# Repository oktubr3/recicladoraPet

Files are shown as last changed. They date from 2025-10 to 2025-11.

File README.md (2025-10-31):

# 🔄 Máquina Recicladora de PET ♻️➡️✨

## 📖 ¿Qué es este proyecto?

Esta máquina transforma botellas de plástico PET (las de gaseosa) en "hilo" para impresoras 3D.

**¿Cómo funciona?** Es como una máquina de hacer fideos, pero con plástico:
1. Cortás tiras de botellas de plástico
2. La máquina las derrite a 240°C (muy caliente!)
3. Un motor va tirando del plástico derretido
4. Sale un "hilo" perfecto para usar en impresoras 3D

**¡Convertimos basura en algo útil!** 🌍💚

---

## 🏗️ ¿Cómo está hecha?

La máquina tiene **DOS partes principales**:

### Parte 1: El Motor (Tira del plástico)
**"El Tractorcito Inteligente" 🚜**

Esta parte tira del plástico derretido, como cuando sacás masa de pizza estirada.

**¿Qué usa?**
- **Motor NEMA 17**: El "músculo" que tira 💪
- **Driver A4988**: Convierte las señales del Arduino en potencia para el motor
- **Arduino Uno**: El "cerebro" que controla todo 🧠
- **Potenciómetro**: Una perilla para controlar la velocidad (como el volumen de la radio)
- **Botón**: Para cambiar la dirección (adelante/atrás)

**¿Qué hace especial?**
- Se mueve SÚPER suave (microstepping 1/16 = pasos 16 veces más pequeños)
- Acelera y frena de forma gradual (no se sacude)
- Podés controlar la velocidad de 0% a 100%

---

### Parte 2: El Calentador (Derrite el plástico)
**"La Cocina de Plástico" 🔥**

Esta parte derrite el plástico PET a 240°C (la temperatura perfecta).

**¿Qué usa?**
- **Hotend V6**: El "horno" que calienta
- **Termistor NTC 100k**: Un "termómetro electrónico" que mide la temperatura
- **Módulo MOSFET**: Un interruptor electrónico que controla cuánta potencia darle al calentador
- **Display LCD**: Una pantallita que muestra la temperatura 📺
- **3 Botones**: Para prender/apagar y subir/bajar la temperatura

**¿Qué hace especial?**
- **Control PID profesional**: Como las impresoras 3D caras (Prusa)
- Llega exactamente a la temperatura que querés (±2-3°C de precisión)
- No se pasa ni se queda corta

---

## 📋 ¿Qué materiales necesito?

### Electrónica:
- [ ] 🧠 Arduino Uno (el cerebro)
- [ ] 💪 Motor NEMA 17 (modelo 17HS2408)
- [ ] 🎮 Driver A4988 (controla el motor)
- [ ] 📺 Display LCD 16x2 con I2C (la pantallita)
- [ ] ⚡ Módulo MOSFET (para controlar el calentador)
- [ ] 🌡️ Termistor NTC 100K (el termómetro)
- [ ] 🎚️ Potenciómetro 10K (la perilla de velocidad)
- [ ] 🔘 4 Botones pulsadores

### Componentes importantes:
- [ ] 🔥 Hotend V6 (el calentador)
- [ ] 🔌 Fuente de alimentación 24V
- [ ] 🔽 Módulo Step-down LM2596 (convierte 24V a 12V)
- [ ] 🔧 Resistencia 4.7kΩ (para el termómetro)
- [ ] ⭐ Resistencia 2.2kΩ (evita que el motor vibre al encender)
- [ ] 🔗 Cable jumper (para conectar 2 pines del A4988)
- [ ] 🛑 Botón de emergencia (para cortar todo en caso de problema)

---

## 🚀 ¿Cómo lo instalo?

### Paso 1: Instalar el programa Arduino IDE 💻
1. 📥 Descargá Arduino IDE desde [arduino.cc](https://www.arduino.cc)
2. 🖱️ Instalalo en tu computadora

### Paso 2: Descargar este proyecto 📦
1. 📥 Descargá este proyecto (botón verde "Code" → "Download ZIP")
2. 📂 Descomprimí el archivo ZIP

### Paso 3: Instalar la biblioteca del display 📚
1. 🖥️ Abrí Arduino IDE
2. 🔧 Andá a: **Herramientas** → **Administrar Bibliotecas**
3. 🔍 Buscá: **"LiquidCrystal I2C"**
4. ✅ Instalá la versión de **Frank de Brabander**

### Paso 4: Subir el código al Arduino ⬆️
1. 📄 Abrí el archivo: `MaquinaRecicladoraPet/MaquinaRecicladoraPet.ino`
2. 🔌 Conectá tu Arduino a la computadora con el cable USB
3. ⚙️ Seleccioná: **Herramientas** → **Placa** → **Arduino Uno**
4. 🔌 Seleccioná: **Herramientas** → **Puerto** → (el puerto donde está tu Arduino)
5. ➡️ Hacé click en el botón **"➜"** (Subir) y esperá ⏳

---

## ⚠️ IMPORTANTE: Configuración de Hardware

### 🔊 Problema común: Motor vibra al encender

Cuando encendés el Arduino, durante los primeros 3 segundos el motor puede vibrar o girar solo. Esto pasa porque los cables "flotan" (no tienen un valor definido) hasta que el programa arranca.

**✅ Solución (OBLIGATORIA):**

#### 1. 🔗 Conectar dos pines del A4988 juntos
En el módulo A4988, buscá los pines **RST** y **SLP** (están uno al lado del otro). Conectalos con un cable o jumper.

#### 2. ⭐ Agregar una resistencia al pin STEP

Esta es LA SOLUCIÓN más importante:

```
                    Cable del Arduino
Arduino D3 ────────────────────┐
                                │
                                ├──── Pin STEP del A4988
                                │
                           [Resistencia
                            2.2kΩ]
                                │
                               GND (tierra)
```

**¿Cómo se conecta?**
- **NO desconectes** el cable que va del Arduino al A4988
- **Agregá** una resistencia de 2.2kΩ entre el pin STEP del A4988 y GND
- La resistencia va "en paralelo" (al costado), no corta el cable
- Podés usar resistencias de: 2.2kΩ, 4.7kΩ o 10kΩ

**¿Por qué funciona?**
La resistencia "tira" el pin hacia GND (0 voltios) cuando el Arduino no está mandando señales. Así el motor no se mueve durante el arranque.

#### 3. 🎯 Conectar los pines de microstepping (IMPORTANTE para movimiento suave)

El microstepping hace que el motor se mueva SÚPER suave, sin vibraciones. Tenés que conectar:

- 📍 **Arduino D8** → **MS1** del A4988
- 📍 **Arduino D12** → **MS2** del A4988
- 📍 **Arduino D13** → **MS3** del A4988

Estos 3 pines le dicen al motor que se mueva en pasos 16 veces más pequeños (3200 pasos por vuelta en vez de 200). ¡Por eso el movimiento es tan suave!

---

## 🎮 ¿Cómo se usa?

### 🎚️ Controlar la velocidad del motor:
- 🔄 Girá el **potenciómetro** (la perilla)
- ➡️ Hacia la derecha = más rápido 🏃
- ⬅️ Hacia la izquierda = más lento 🐢
- 🛑 Si lo ponés en 0%, el motor se apaga solo

### 🔀 Cambiar la dirección:
- 🔘 Presioná el **botón conectado al pin D4**
- ↔️ El motor cambia entre adelante y atrás

### 🌡️ Controlar la temperatura:
- 🔘 **Botón conectado al pin D5**: Prender/Apagar el calentador 🔥
- 🔘 **Botón conectado al pin D6**: Bajar temperatura (de a 5°C) ❄️
- 🔘 **Botón conectado al pin D7**: Subir temperatura (de a 5°C) 🔥
- 🎯 Temperatura inicial: **240°C** (perfecta para PET)

### 📺 Leer el display:
**Pantalla normal** (muestra la temperatura):
```
T:240.0C  [ON]
Obj:240C
```
- 🌡️ **T:** = Temperatura actual
- 🔥 **[ON]** = Está calentando
- ✅ **[--]** = Está en la temperatura correcta (esperando)
- ⭕ **[OFF]** = Apagado
- 🎯 **Obj:** = Temperatura objetivo

**Pantalla temporal** (cuando ajustás la velocidad):
```
Velocidad:  50%
Dir: Adelante
```
o
```
Velocidad:  50%
Dir: Atras
```
⏱️ Esta pantalla se muestra por 3 segundos cuando tocás el potenciómetro o el botón de dirección.

---

## 🔧 Solución de problemas

### 🔊 El motor vibra cuando enciendo el Arduino

**❓ Causa:** Los cables "flotan" durante los primeros 3 segundos del arranque.

**✅ Solución:**
1. ❓ ¿Conectaste los pines **RST y SLP** del A4988?
2. ❓ ¿Agregaste la **resistencia 2.2kΩ** entre STEP y GND?
3. ❓ ¿La resistencia está en **paralelo** (no corta el cable del Arduino)?

✨ Si hiciste todo eso, el motor NO debería moverse al encender.

---

### 🔊 El motor vibra TODO el tiempo

**❓ Posibles causas:**
1. **⚙️ Microstepping mal configurado:**
   - Verificá que los pines **D8, D12, D13** del Arduino estén conectados a **MS1, MS2, MS3** del A4988
   - Estos pines controlan el modo de microstepping (1/16 step = movimiento súper suave)

2. **⚡ Poca corriente:**
   - El potenciómetro del A4988 (VREF) debe estar en 0.8V
   - Si no tenés multímetro, giralo POQUITO en sentido horario

3. **🔗 RST y SLP no conectados:**
   - Verificá que esos dos pines estén conectados con un jumper

---

### 📺 El display no muestra nada

**✅ Soluciones:**
1. **🎚️ Ajustar el contraste:** En la parte de atrás del display hay un potenciómetro chiquito. Giralo hasta que veas las letras.
2. **📍 Dirección I2C incorrecta:**
   - 🖥️ Abrí el código en Arduino IDE
   - 🔍 Buscá la línea 34: `LiquidCrystal_I2C lcd(0x27, 16, 2);`
   - 🔄 Cambiá `0x27` por `0x3F`
   - ⬆️ Volvé a subir el código

---

### 🌡️ La temperatura no es correcta

1. 🔍 **Verificá las conexiones del termistor** (el sensor de temperatura)
2. 🔧 **Verificá la resistencia de 4.7kΩ** (debe estar bien conectada)
3. 🏠 La temperatura ambiente debería mostrar entre 18°C y 25°C

---

## 📊 Datos técnicos (para los curiosos) 🤓

### 🎮 Motor:
- ⚙️ **Pasos por vuelta:** 3200 (con microstepping 1/16)
- 🏃 **Velocidad:** Ajustable de 100 a 2000 RPM
- ✨ **Suavidad:** Movimiento ultra suave, sin vibraciones
- 🚀 **Aceleración:** Gradual (no se sacude al arrancar/frenar)

### 🌡️ Temperatura:
- 📏 **Rango:** 0°C a 270°C
- 🎯 **Precisión:** ±2-3°C
- 🧠 **Control:** PID profesional (como impresoras 3D Prusa)
- 🔥 **Temperatura para PET:** 240°C

### 📺 Display:
- 📐 **Tamaño:** 16 caracteres × 2 líneas
- ⚡ **Actualización:** Cada 0.2 segundos (sin parpadeo)

---

## 🛡️ Seguridad

**⚠️ IMPORTANTE - LEÉ ESTO:**

1. 🔥 **El calentador llega a 240°C** (¡puede quemarte!):
   - 🚫 NO lo toques cuando está encendido
   - ⏰ Esperá 10 minutos después de apagar para que se enfríe

2. 🛑 **Botón de emergencia**:
   - ✅ Siempre tené el botón de emergencia conectado
   - ⚡ Si algo sale mal, presionalo y corta toda la energía

3. 👨‍👩‍👧 **Supervisión de un adulto**:
   - ⚠️ Este proyecto usa temperaturas altas y electricidad
   - 🤝 Pedile a un adulto que te supervise

4. 💨 **Ventilación**:
   - 🪟 Usá la máquina en un lugar ventilado
   - 👃 El plástico derretido puede tener olor

---

## 🎓 ¿Querés aprender más?

### 🤖 Sobre Arduino:
- 📚 [Documentación oficial de Arduino](https://www.arduino.cc/reference/es/)
- 🎥 [Tutoriales en español](https://www.arduino.cc/en/Tutorial/HomePage)

### ♻️ Sobre el PET:
- 🔬 [¿Qué es el PET?](https://es.wikipedia.org/wiki/Tereftalato_de_polietileno)
- 🥤 El PET es el plástico de las botellas de gaseosa
- 🌡️ Se derrite a 240-260°C

### 🌍 Sobre reciclaje:
- ♻️ [Precious Plastic](https://preciousplastic.com/) - Proyecto de reciclaje de plástico global
- 🤖 [Recyclebot](https://www.appropedia.org/Recyclebot) - Máquinas similares

---

## 💚 Misión del proyecto

**🌍 Queremos ayudar al planeta** convirtiendo botellas de plástico (que iban a la basura) en material útil para crear cosas nuevas con impresoras 3D.

Si cada persona recicla sus botellas, podemos:
- 🗑️ Reducir la basura plástica
- 🎨 Crear material útil
- 💰 Ahorrar dinero
- 🌳 Proteger el medio ambiente

**¡Juntos podemos convertir la basura en tesoros!** 🌍♻️✨

---

## 📄 Licencia

Este proyecto es **libre y gratuito** (Licencia MIT). Podés:
- ✅ Usarlo para lo que quieras
- 🔧 Modificarlo
- 🤝 Compartirlo
- 🏗️ Construir tu propia máquina

---

## 👥 Créditos

Creado con ❤️ para ayudar al planeta 🌍 y enseñar programación 💻.

---

**❓ ¿Preguntas? 🐛 ¿Problemas? 💡 ¿Mejoras?**
Abrí un "Issue" en GitHub y te ayudamos! 🚀

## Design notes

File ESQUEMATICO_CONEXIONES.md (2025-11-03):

# 🔌 Esquemático de Conexiones - Máquina Recicladora PET

## 📋 Tabla de Conexiones Completa

### 🎮 Motor NEMA 17 + Driver A4988

| Arduino Pin | →  | A4988 Pin | Descripción |
|---|---|---|---|
| **D2** | → | **DIR** | Dirección del motor (adelante/atrás) |
| **D3** | → | **STEP** | Pasos del motor (cada pulso = 1 paso) |
| **D8** | → | **MS1** | Microstepping bit 1 |
| **D12** | → | **MS2** | Microstepping bit 2 |
| **D13** | → | **MS3** | Microstepping bit 3 |
| **5V** | → | **VDD** | Alimentación lógica del driver |
| **GND** | → | **GND** | Tierra común |

**⚠️ IMPORTANTE - Resistencia Pull-Down:**
```
Pin STEP (A4988) ──┬──→ Arduino D3
                   │
              [Resistencia
               2.2kΩ]
                   │
                  GND
```

**🔗 Jumper RST-SLP:**
- Conectar con un cable jumper: **RST ↔ SLP** (pines del A4988)

**⚡ Alimentación del motor:**
- **12V+** → **VMOT** del A4988
- **GND** → **GND** del A4988

**🔌 Salidas del motor:**
- A4988 **1A, 1B, 2A, 2B** → Motor NEMA 17 (4 cables)

---

### 🌡️ Sistema de Calefacción (Hotend V6)

| Componente | Pin | →  | Destino |
|---|-----|---|---|
| **Termistor NTC 100K** | Cable 1 | → | **A1** (Arduino) |
| **Termistor NTC 100K** | Cable 2 | → | **5V** |
| **Resistencia 4.7kΩ** | Terminal 1 | → | **A1** (Arduino) |
| **Resistencia 4.7kΩ** | Terminal 2 | → | **GND** |

**Circuito del Termistor:**
```
5V ─────┬──── Termistor ────┬──── A1 (Arduino)
        │                    │
        │              [Resistencia
        │                4.7kΩ]
        │                    │
        └────────────────────┴──── GND
```

| Módulo MOSFET | Pin | →  | Destino |
|---|-----|---|---|
| **MOSFET** | Signal (S) | → | **D11** (Arduino - PWM) |
| **MOSFET** | VCC | → | **5V** (Arduino) |
| **MOSFET** | GND | → | **GND** (Arduino) |
| **MOSFET** | V+ | → | **24V+** (Fuente) |
| **MOSFET** | V- | → | **GND** (Fuente) |
| **MOSFET** | OUT+ | → | **Hotend V6 +** |
| **MOSFET** | OUT- | → | **Hotend V6 -** |

---

### 📺 Display LCD 16x2 con I2C

| LCD I2C | Pin | →  | Arduino Pin |
|---|-----|---|---|
| **VCC** | | → | **5V** |
| **GND** | | → | **GND** |
| **SDA** | | → | **A4** (o pin SDA) |
| **SCL** | | → | **A5** (o pin SCL) |

---

### 🎚️ Potenciómetro (Control de Velocidad)

| Potenciómetro 10K | Pin | →  | Destino |
|---|-----|---|---|
| Terminal 1 | | → | **GND** |
| Terminal central (wiper) | | → | **A0** (Arduino) |
| Terminal 3 | | → | **5V** |

---

### 🔘 Botones de Control

| Botón | Pin | →  | Arduino Pin | Función |
|---|-----|---|---|---|
| **Botón 1** | Terminal 1 | → | **D4** | Cambiar dirección motor |
| **Botón 1** | Terminal 2 | → | **GND** | |
| **Botón 2** | Terminal 1 | → | **D5** | ON/OFF calefactor |
| **Botón 2** | Terminal 2 | → | **GND** | |
| **Botón 3** | Terminal 1 | → | **D6** | Bajar temperatura (-5°C) |
| **Botón 3** | Terminal 2 | → | **GND** | |
| **Botón 4** | Terminal 1 | → | **D7** | Subir temperatura (+5°C) |
| **Botón 4** | Terminal 2 | → | **GND** | |

**📝 Nota:** Los botones usan la resistencia pull-up interna del Arduino (INPUT_PULLUP), por eso van directo a GND.

---

### ⚡ Sistema de Alimentación

| Fuente | Salida | →  | Destino |
|---|---|---|---|
| **Fuente 24V** | 24V+ | → | VMOT (A4988) + Entrada Step-Down |
| **Fuente 24V** | GND | → | GND común |
| **Step-Down LM2596** | Entrada | ← | 24V (Fuente) |
| **Step-Down LM2596** | Salida 12V | → | Arduino Vin |
| **Step-Down LM2596** | GND | → | GND común |

---

## 🎨 Diagrama Visual Simplificado

```
                    ARDUINO UNO
        ┌──────────────────────────────────┐
        │                                  │
        │  D2  ────────────→ DIR (A4988)  │
        │  D3  ─┬──────────→ STEP (A4988) │
        │       │                          │
        │       └─[2.2kΩ]─→ GND            │
        │                                  │
        │  D4  ←───[Botón]──→ GND          │
        │  D5  ←───[Botón]──→ GND          │
        │  D6  ←───[Botón]──→ GND          │
        │  D7  ←───[Botón]──→ GND          │
        │                                  │
        │  D8  ────────────→ MS1 (A4988)   │
        │  D11 ────────────→ MOSFET Signal │
        │  D12 ────────────→ MS2 (A4988)   │
        │  D13 ────────────→ MS3 (A4988)   │
        │                                  │
        │  A0  ←───[Pot]────┬─ 5V          │
        │                   └─ GND         │
        │                                  │
        │  A1  ←───[Termistor + 4.7kΩ]─┬─ 5V
        │                               └─ GND
        │                                  │
        │  A4  ←─────────── SDA (LCD)      │
        │  A5  ←─────────── SCL (LCD)      │
        │                                  │
        │  5V  ────┬────────────────────   │
        │          ├→ LCD VCC              │
        │          ├→ A4988 VDD            │
        │          ├→ MOSFET VCC           │
        │          └→ Pot + Termistor      │
        │                                  │
        │  GND ────┴────────────────────   │
        │          └→ Común a todos        │
        │                                  │
        │  Vin ←─── 12V (Step-Down)        │
        └──────────────────────────────────┘

        A4988 Driver
        ┌──────────────┐
        │ VMOT ← 24V   │
        │ GND  ← GND   │
        │ 1A,1B,2A,2B  │──→ NEMA 17
        │ RST↔SLP      │ (con jumper)
        └──────────────┘

        MOSFET Module
        ┌──────────────┐
        │ V+ ← 24V     │
        │ V- ← GND     │
        │ OUT+,OUT-    │──→ Hotend V6
        └──────────────┘
```

---

## ✅ Lista de Verificación de Conexiones

Antes de encender, verificá:

- [ ] 🔌 Todos los GND están conectados (tierra común)
- [ ] ⚡ Fuente de 24V conectada correctamente
- [ ] 🔽 Step-down configurado en 12V de salida
- [ ] 🔗 Resistencia 2.2kΩ entre STEP y GND (pull-down)
- [ ] 🔗 Jumper RST-SLP en el A4988
- [ ] 📍 Pines MS1, MS2, MS3 conectados (D8, D12, D13)
- [ ] 🌡️ Termistor con resistencia 4.7kΩ a GND
- [ ] 📺 Display I2C en pines correctos (A4=SDA, A5=SCL)
- [ ] 🔘 Los 4 botones conectados a GND
- [ ] 🎚️ Potenciómetro entre GND y 5V, centro a A0
- [ ] 🔥 Hotend conectado al MOSFET (respetando polaridad)
- [ ] 💪 Motor NEMA 17 conectado al A4988

---

## 🎯 Configuración del Driver A4988

### Ajuste de Corriente (VREF)

El potenciómetro pequeño en el A4988 controla la corriente del motor:

**Para NEMA 17 (17HS2408):**
- **VREF recomendado:** 0.8V
- **Fórmula:** VREF = Corriente_motor × 8 × R_sense
- Para 1A: VREF = 1.0 × 8 × 0.1 = 0.8V

**🔧 Cómo medir:**
1. Conectá el multímetro en modo voltaje DC
2. Cable negro (COM) → GND del A4988
3. Cable rojo → Tornillo del potenciómetro
4. Girá el potenciómetro hasta ver 0.8V
5. Girá en sentido horario para aumentar
6. Girá en sentido antihorario para disminuir

---

## 🛡️ Seguridad

⚠️ **IMPORTANTE:**

1. **SIEMPRE desconectá la alimentación** antes de hacer cambios
2. **Verificá polaridad** del hotend y motor antes de conectar
3. **NO toques** el A4988 ni el hotend cuando estén encendidos (se calientan mucho)
4. **Botón de emergencia:** Mantené un botón para cortar la alimentación rápidamente
5. **Ventilación:** Trabajá en un lugar ventilado
6. **Supervisión adulta:** Este proyecto maneja altas temperaturas y voltajes

---

## 📸 Fotos Recomendadas (para agregar después)

Para hacer este manual más completo, sería útil agregar fotos de:
- [ ] Conexiones del A4988 con todos los cables
- [ ] Circuito del termistor con la resistencia
- [ ] Módulo MOSFET conectado
- [ ] Display LCD con cables I2C
- [ ] Potenciómetro conectado
- [ ] Vista general del circuito armado

---

**✨ Con estas conexiones, tu máquina recicladora estará lista para funcionar!**

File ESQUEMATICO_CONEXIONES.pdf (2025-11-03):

## 🔌 Esquemático de Conexiones - Máquina Recicladora PET

### 📋 Tabla de Conexiones Completa

🎮 Motor NEMA 17 + Driver A4988

Arduino Pin | → | A4988 Pin | Descripción
D2 | → | DIR | Dirección del motor (adelante/atrás)
D3 | → | STEP | Pasos del motor (cada pulso = 1 paso)
D8 | → | MS1 | Microstepping bit 1
D12 | → | MS2 | Microstepping bit 2
D13 | → | MS3 | Microstepping bit 3
5V | → | VDD | Alimentación lógica del driver
GND | → | GND | Tierra común

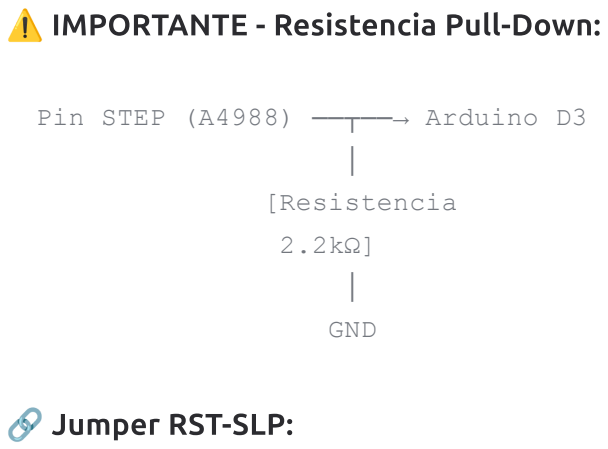
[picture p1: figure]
⚠️ IMPORTANTE - Resistencia Pull-Down:; 🔗 Jumper RST-SLP:; Pin STEP (A4988) ──┬──→ Arduino D3 │ [Resistencia 2.2kΩ] │ GND

Conectar con un cable jumper: RST ↔ SLP (pines del A4988)

⚡ Alimentación del motor:

12V+ → VMOT del A4988

GND → GND del A4988

🔌 Salidas del motor:

A4988 1A, 1B, 2A, 2B → Motor NEMA 17 (4 cables)

️ Sistema de Calefacción (Hotend V6)

Componente | Pin | → | Destino
Termistor NTC 100K | Cable 1 | → | A1 (Arduino)
Termistor NTC 100K | Cable 2 | → | 5V
Resistencia 4.7kΩ | Terminal 1 | → | A1 (Arduino)
Resistencia 4.7kΩ | Terminal 2 | → | GND

Circuito del Termistor:

Módulo MOSFET | Pin | → | Destino
MOSFET | Signal (S) | → | D11 (Arduino - PWM)
MOSFET | VCC | → | 5V (Arduino)
MOSFET | GND | → | GND (Arduino)
MOSFET | V+ | → | 24V+ (Fuente)
MOSFET | V- | → | GND (Fuente)
MOSFET | OUT+ | → | Hotend V6 +
MOSFET | OUT- | → | Hotend V6 -

📺 Display LCD 16x2 con I2C

## 5V ─────┬──── Termistor ────┬──── A1 (Arduino)

│ | │
│ | [Resistencia
│ | 4.7kΩ]
│ | │

## └────────────────────┴──── GND

LCD I2C | Pin | → | Arduino Pin
VCC | | → | 5V
GND | | → | GND
SDA | | → | A4 (o pin SDA)
SCL | | → | A5 (o pin SCL)

️ Potenciómetro (Control de Velocidad)

Potenciómetro 10K | Pin | → | Destino
Terminal 1 | | → | GND
Terminal central (wiper) | | → | A0 (Arduino)
Terminal 3 | | → | 5V

🔘 Botones de Control

Botón | Pin | → | Arduino Pin | Función
Botón 1 | Terminal 1 | → | D4 | Cambiar dirección motor
Botón 1 | Terminal 2 | → | GND
Botón 2 | Terminal 1 | → | D5 | ON/OFF calefactor
Botón 2 | Terminal 2 | → | GND
Botón 3 | Terminal 1 | → | D6 | Bajar temperatura (-5°C)
Botón 3 | Terminal 2 | → | GND
Botón 4 | Terminal 1 | → | D7 | Subir temperatura (+5°C)

Botón | Pin | → | Arduino Pin | Función
Botón 4 | Terminal 2 | → | GND

📝 Nota: Los botones usan la resistencia pull-up interna del Arduino (INPUT_PULLUP), por eso van

directo a GND.

⚡ Sistema de Alimentación

Fuente | Salida | → | Destino
Fuente 24V | 24V+ | → | VMOT (A4988) + Entrada Step-Down
Fuente 24V | GND | → | GND común
Step-Down LM2596 | Entrada | ← | 24V (Fuente)
Step-Down LM2596 | Salida 12V | → | Arduino Vin
Step-Down LM2596 | GND | → | GND común

### 🎨 Diagrama Visual Simplificado

## ARDUINO UNO

┌──────────────────────────────────┐
│ | | │

## │ D2 ────────────→ DIR (A4988) │ │ D3 ─┬──────────→ STEP (A4988) │

│ | │ | │
│ | └─[2.2kΩ]─→ GND | │
│ | | │
│ D4 ←───[Botón]──→ GND | │
│ D5 ←───[Botón]──→ GND | │
│ D6 ←───[Botón]──→ GND | │
│ D7 ←───[Botón]──→ GND | │
│ | | │
│ D8 ────────────→ MS1 (A4988) | │

## │ D11 ────────────→ MOSFET Signal │

### ✅ Lista de Verificación de Conexiones

Antes de encender, verificá:

│ D12 ────────────→ MS2 (A4988) | │
│ D13 ────────────→ MS3 (A4988) | │
│ | | │
│ A0 ←───[Pot]────┬─ 5V | │
│ | └─ GND | │
│ | | │

## │ A1 ←───[Termistor + 4.7kΩ]─┬─ 5V

│ | | └─ GND
│ | | │
│ A4 ←─────────── SDA (LCD) | │
│ A5 ←─────────── SCL (LCD) | │
│ | | │
│ 5V ────┬──────────────────── | │
│ | ├→ LCD VCC | │
│ | ├→ A4988 VDD | │
│ | ├→ MOSFET VCC | │
│ | └→ Pot + Termistor | │
│ | | │
│ GND ────┴──────────────────── | │
│ | └→ Común a todos | │
│ | | │
│ Vin ←─── 12V (Step-Down) | │
└──────────────────────────────────┘

## A4988 Driver

┌──────────────┐
│ VMOT ← 24V | │
│ GND ← GND | │

## │ 1A,1B,2A,2B │──→ NEMA 17

│ RST↔SLP | │ (con jumper)
└──────────────┘

## MOSFET Module

┌──────────────┐
│ V+ ← 24V | │
│ V- ← GND | │
│ OUT+,OUT- | │──→ Hotend V6
└──────────────┘

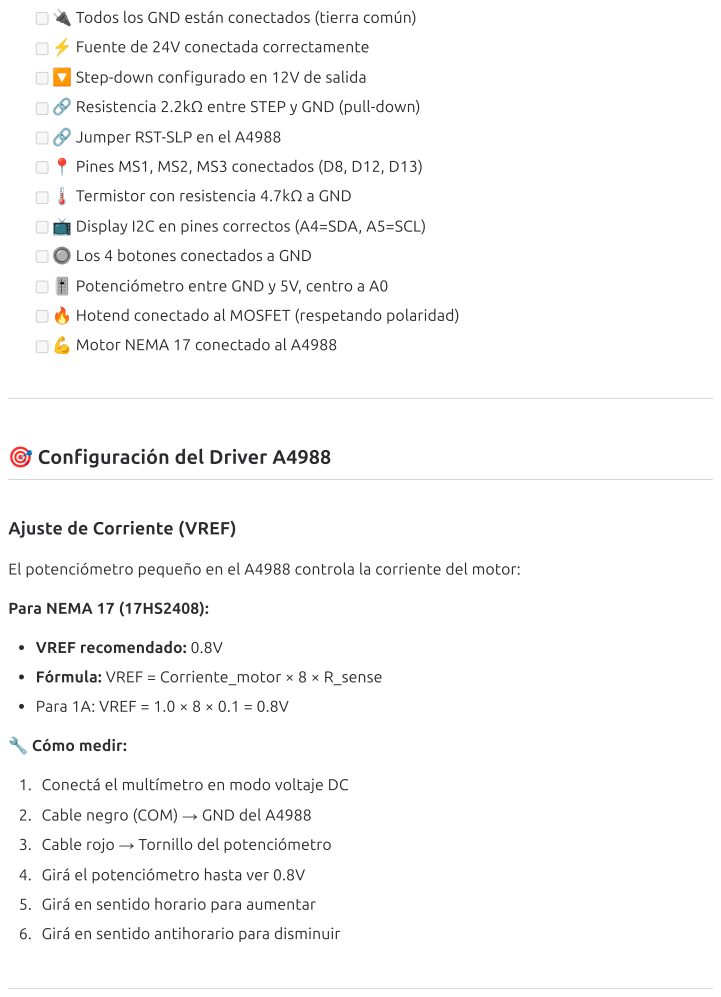
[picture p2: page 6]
📍 Pines MS1, MS2, MS3 conectados (D8, D12, D13); Para NEMA 17 (17HS2408):; VREF recomendado: 0.8V; Fórmula: VREF = Corriente_motor × 8 × R_sense; Para 1A: VREF = 1.0 × 8 × 0.1 = 0.8V; 🔧 Cómo medir:

🔌 Todos los GND están conectados (tierra común)

⚡ Fuente de 24V conectada correctamente

🔽 Step-down configurado en 12V de salida

🔗 Resistencia 2.2kΩ entre STEP y GND (pull-down)

🔗 Jumper RST-SLP en el A4988

️ Termistor con resistencia 4.7kΩ a GND

📺 Display I2C en pines correctos (A4=SDA, A5=SCL)

🔘 Los 4 botones conectados a GND

️ Potenciómetro entre GND y 5V, centro a A0

🔥 Hotend conectado al MOSFET (respetando polaridad)

💪 Motor NEMA 17 conectado al A4988

🎯 Configuración del Driver A4988

Ajuste de Corriente (VREF)

El potenciómetro pequeño en el A4988 controla la corriente del motor:

1. Conectá el multímetro en modo voltaje DC

2. Cable negro (COM) → GND del A4988

3. Cable rojo → Tornillo del potenciómetro

4. Girá el potenciómetro hasta ver 0.8V

5. Girá en sentido horario para aumentar

6. Girá en sentido antihorario para disminuir

### ️ Seguridad

⚠️ IMPORTANTE:

1. SIEMPRE desconectá la alimentación antes de hacer cambios
2. Verificá polaridad del hotend y motor antes de conectar
3. NO toques el A4988 ni el hotend cuando estén encendidos (se calientan mucho)
4. Botón de emergencia: Mantené un botón para cortar la alimentación rápidamente
5. Ventilación: Trabajá en un lugar ventilado
6. Supervisión adulta: Este proyecto maneja altas temperaturas y voltajes

### 📸 Fotos Recomendadas (para agregar después)

Para hacer este manual más completo, sería útil agregar fotos de:

Conexiones del A4988 con todos los cables

Circuito del termistor con la resistencia

Módulo MOSFET conectado

Display LCD con cables I2C

Potenciómetro conectado

Vista general del circuito armado

✨ Con estas conexiones, tu máquina recicladora estará lista para funcionar!

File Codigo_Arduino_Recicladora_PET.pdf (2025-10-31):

// ============================================
// 🎯 ¡MÁQUINA RECICLADORA DE BOTELLAS DE PLÁSTICO!
// ============================================
// Este programa controla una máquina que transforma botellas de plástico PET
// en "hilo" para impresoras 3D. ¡Es como una máquina de hacer fideos, pero con plástico! //
// La máquina tiene 2 partes principales:
// 1. Un MOTOR que tira del plástico derretido (como tirar masa de pizza)
// 2. Un CALEFACTOR que derrite el plástico a 240°C (como un horno)
//
// El Arduino es el "cerebro" que controla todo automáticamente.
// ============================================

// ============================================
// PASO 1: INCLUIR LIBRERÍAS
// ============================================
// Las librerías son como "cajas de herramientas" que otras personas ya hicieron
// y nosotros podemos usar. Nos ahorran mucho trabajo.
#include <Wire.h> | // Esta librería permite hablar con el display por I2C

// I2C es como un "idioma" que usa solo 2 cables para comunicarse

#include <LiquidCrystal_I2C.h> // Esta librería controla el display LCD (la pantallita) // LCD = Liquid Crystal Display (pantalla de cristal líquido)

// ============================================
// PASO 2: CONFIGURAR EL DISPLAY LCD
// ============================================
// Creamos un objeto llamado "lcd" que representa nuestra pantalla.
// Es como ponerle un nombre a la pantalla para poder hablarle.

LiquidCrystal_I2C lcd(0x27, 16, 2); // 0x27 es la "dirección" del display (como una dirección de casa)
// 16 = tiene 16 columnas (16 letras por fila) // 2 = tiene 2 filas (2 líneas de texto)
// Si no funciona, prueba cambiar 0x27 por 0x3F

// ============================================
// PASO 3: DEFINIR LOS PINES DEL MOTOR
// ============================================
// Los "pines" son como los enchufes del Arduino donde conectamos cables. // Cada pin tiene un número, como si fueran "apartamentos" numerados.

const int dirPin = 2; // Pin número 2: controla la DIRECCIÓN del motor // Le dice al motor si debe girar hacia adelante o hacia atrás // "const" significa que este número NUNCA va a cambiar

const int stepPin = 3; // Pin número 3: controla los PASOS del motor // Cada vez que este pin cambia, el motor da "un pasito"
// Es como cuando caminas: cada paso te mueve un poquito

// --- PINES DE MICROSTEPPING (¡NUEVO! Para eliminar vibración) ---

// Estos 3 pines controlan cuán "suave" se mueve el motor. // MS1, MS2, MS3 = MicroStep 1, 2, 3
// Los ponemos en HIGH para activar modo 1/16 (súper suave)
const int ms1Pin = 8; | // Pin 8: conectado a MS1 del A4988
const int ms2Pin = 12; | // Pin 12: conectado a MS2 del A4988
const int ms3Pin = 13; | // Pin 13: conectado a MS3 del A4988

// Tabla de microstepping del A4988:
// MS1 MS2 MS3 → Modo
// LOW LOW LOW → Full step (1/1) | ← modo viejo (mucha vibración)
// HIGH HIGH HIGH → 1/16 step | ← modo nuevo (súper suave)

// ============================================
// PASO 4: DEFINIR EL PIN DEL POTENCIÓMETRO
// ============================================
// El potenciómetro es la "perilla giratoria" para controlar la velocidad.
// Es como el acelerador de un auto o el control de volumen de la radio.

const int potPin = A0; // Pin A0 (es un pin "analógico", lee valores de 0 a 1023) // Cuando giramos la perilla, este pin lee un número diferente

// ============================================
// PASO 5: VARIABLES PARA EL MOTOR (INTERRUPCIONES)
// ============================================
// Estas variables controlan cómo funciona el motor.
// "volatile" es una palabra especial que significa: "esta variable puede cambiar
// en cualquier momento por una interrupción, ¡así que no la optimices!"

volatile unsigned int motorDelayMicros = 5000; // Tiempo entre cada paso del motor (en microsegundos)
// Cuanto MÁS PEQUEÑO el número = motor MÁS RÁPIDO
// 5000 microsegundos = 0.005 segundos

volatile bool motorHabilitado = true; // "bool" = variable que solo puede ser true (verdadero) o false (falso)
// true = motor ENCENDIDO, false = motor APAGADO

// --- VARIABLES PARA ACELERACIÓN SUAVE (¡NUEVO! Para evitar sacudidas) ---
// En vez de cambiar la velocidad instantáneamente, la cambiamos gradualmente.
// Es como acelerar un auto suavemente en vez de pisar a fondo de golpe.

volatile unsigned int motorDelayObjetivo = 5000; // Velocidad a la que QUEREMOS llegar
volatile unsigned int motorDelayActual = 5000; | // Velocidad ACTUAL del motor
const unsigned int pasoAceleracion = 50; | // Qué tan rápido acelera (50 = suave)
// Valor más chico = aceleración más suave
// Valor más grande = aceleración más brusca

// ============================================
// PASO 6: DEFINIR PINES Y VALORES DEL TERMISTOR
// ============================================
// El termistor es un "termómetro electrónico" que mide la temperatura.

// Es como un sensor mágico que cambia su resistencia cuando cambia la temperatura.

const int termistorPin = A1; | // Pin A1: aquí leemos la temperatura
const float R_FIJA = 4700.0; | // Resistencia fija de 4700 ohmios (4.7k)
// Esta resistencia está conectada en serie con el termistor
// "float" = número decimal (puede tener comas, como 4.5)

const float R_TERMISTOR_25C = 100000.0; // A 25°C, el termistor tiene 100,000 ohmios (100k)
// Es como su "valor de referencia"
const float BETA = 3950.0; | // Número mágico del termistor (dato del
fabricante)
// Se usa en la fórmula matemática para calcular temperatura

// ============================================
// PASO 7: DEFINIR PIN Y VARIABLES DEL CALEFACTOR
// ============================================
// El MOSFET es como un "interruptor electrónico" que controla el calefactor.
// Puede apagarlo, encenderlo, o ponerlo a "media potencia".
const int mosfetPin = 11; | // Pin 11: controla la potencia del calefactor
// Usa PWM (Pulse Width Modulation) = control de potencia variable
// Es como un interruptor que prende y apaga SUPER rápido
float tempObjetivo = 240.0; | // Temperatura que QUEREMOS alcanzar (en grados
Celsius)
// 240°C es perfecto para derretir PET (plástico de botellas)

bool controlCalefactorActivo = false; // ¿Está el control automático ENCENDIDO? // false = apagado, true = encendido

// ============================================
// PASO 8: VARIABLES DEL CONTROL PID
// ============================================
// PID es un "piloto automático inteligente" que controla la temperatura.
// Es como el control de crucero de un auto, pero para temperatura.
// PID significa: Proporcional, Integral, Derivativo (son 3 tipos de correcciones)

float Kp = 8.0; // "Proporcional": cuánto reaccionar según QUÉ TAN LEJOS estamos del objetivo
// Si estamos MUY lejos = corregir MUCHO
// Si estamos cerca = corregir poquito

float Ki = 0.05; // "Integral": corregir errores que SE ACUMULAN con el tiempo // Es como compensar por quedarse siempre un poquito abajo del objetivo

float Kd = 120.0; // "Derivativo": ANTICIPAR y frenar ANTES de llegar al objetivo

// Es como frenar el auto ANTES de llegar al semáforo // ¡Evita que nos "pasemos" de temperatura!

float errorAnterior = 0.0; // Guardamos cuál era el error la última vez (para calcular "D")
float errorAcumulado = 0.0; // Guardamos la SUMA de todos los errores (para calcular "I")

// ============================================
// PASO 9: DEFINIR PINES DE LOS BOTONES
// ============================================
// Los botones son como "interruptores" que presionamos con el dedo.
const int botonOnOff = 5; | // Pin 5: botón para PRENDER/APAGAR el control de temperatura
const int botonBajar = 6; | // Pin 6: botón para BAJAR la temperatura objetivo (-5°C)
const int botonSubir = 7; | // Pin 7: botón para SUBIR la temperatura objetivo (+5°C)
const int botonInversion = 4; | // Pin 4: botón para cambiar la DIRECCIÓN del motor
// Hace que el motor gire al revés

bool direccionActual = LOW; // Guardamos en qué dirección va el motor por defecto // LOW = dirección por defecto, HIGH = invertida

// ============================================
// PASO 10: VARIABLE PARA LAS INTERRUPCIONES
// ============================================
// Esta variable se usa en la "interrupción" que mueve el motor.
// Una interrupción es como una "alarma" que suena automáticamente.

volatile bool pulsoAlto = false; // ¿El pulso del motor está en HIGH o LOW? // El motor necesita que este valor alterne: HIGH, LOW, HIGH, LOW...

// ============================================
// PASO 11: FUNCIÓN DE INTERRUPCIÓN (ISR)
// ============================================
// ISR = Interrupt Service Routine = "Rutina de Servicio de Interrupción"
// Esta función se ejecuta AUTOMÁTICAMENTE cada cierto tiempo, como un despertador. // NO la llamamos nosotros, ¡el Timer1 la llama solito!
//
// ¿Para qué sirve? Para mover el motor SIN BLOQUEAR el resto del programa.
// Es como poder caminar Y masticar chicle al mismo tiempo.

ISR(TIMER1_COMPA_vect) {
// Esta función se ejecuta automáticamente cada pocos microsegundos

if (motorHabilitado) { // Solo si el motor está habilitado...

// --- ACELERACIÓN SUAVE (¡NUEVO!) ---
// Cada vez que se ejecuta la ISR, acercamos la velocidad actual a la velocidad objetivo.
// Es como acelerar gradualmente un auto en vez de pisar a fondo de golpe.

if (motorDelayActual > motorDelayObjetivo) {
// Si vamos más LENTO de lo que queremos → ACELERAR

// (delay más grande = velocidad más lenta)
motorDelayActual -= pasoAceleracion; // Reducir el delay = ir más rápido if (motorDelayActual < motorDelayObjetivo) {
motorDelayActual = motorDelayObjetivo; // No pasarse del objetivo
}
OCR1A = motorDelayActual * 2; // Actualizar la velocidad del timer

} else if (motorDelayActual < motorDelayObjetivo) {
// Si vamos más RÁPIDO de lo que queremos → DESACELERAR motorDelayActual += pasoAceleracion; // Aumentar el delay = ir más lento if (motorDelayActual > motorDelayObjetivo) {
motorDelayActual = motorDelayObjetivo; // No pasarse del objetivo
}
OCR1A = motorDelayActual * 2; // Actualizar la velocidad del timer }

// --- GENERAR PULSO PARA EL MOTOR ---
// Alternamos el pin del motor entre HIGH y LOW
// Es como prender y apagar una luz super rápido: PRENDIDO-APAGADO-PRENDIDO-APAGADO // Cada vez que cambia, el motor da "un pasito"

if (pulsoAlto) {
// Si el pulso está en HIGH, lo bajamos a LOW
digitalWrite(stepPin, LOW); | // Apagar el pin
pulsoAlto = false; | // Recordar que ahora está en LOW
} else {
// Si el pulso está en LOW, lo subimos a HIGH digitalWrite(stepPin, HIGH); // Encender el pin
pulsoAlto = true; | // Recordar que ahora está en HIGH
}
}
}

// ============================================
// PASO 12: FUNCIÓN SETUP (SE EJECUTA UNA SOLA VEZ)
// ============================================
// La función "setup" es como el "despertarse por la mañana" del Arduino. // Se ejecuta UNA SOLA VEZ cuando enciendes el Arduino.
// Aquí configuramos TODO antes de empezar a trabajar.

void setup() {

// --- PASO 12.1: ENCENDER Y CONFIGURAR EL DISPLAY ---
lcd.init(); | // "init" = inicializar = "despertá, pantalla!"
lcd.backlight(); // Encender la luz de fondo (para poder ver las letras)

// Mostrar mensaje de bienvenida
lcd.setCursor(0, 0); | // Ir a la columna 0, fila 0 (esquina superior
izquierda)
lcd.print("Recicladora PET"); | // Escribir texto en el display
lcd.setCursor(0, 1); | // Ir a la columna 0, fila 1 (segunda línea)
lcd.print("Iniciando..."); | // Escribir texto en el display
delay(1500); | // Esperar 1.5 segundos (1500 milisegundos)
// Para que podamos leer el mensaje

lcd.clear(); // Borrar todo el display (dejarlo en blanco)

// --- PASO 12.2: CONFIGURAR LOS PINES DEL MOTOR ---
// "pinMode" le dice al Arduino: "este pin va a DAR órdenes (OUTPUT)"
pinMode(dirPin, OUTPUT); | // Pin 2 es SALIDA (nosotros mandamos señales)
pinMode(stepPin, OUTPUT); | // Pin 3 es SALIDA (nosotros mandamos señales)

// ¡NUEVO! Configurar pines de microstepping
pinMode(ms1Pin, OUTPUT); | // Pin 8 es SALIDA
pinMode(ms2Pin, OUTPUT); | // Pin 12 es SALIDA
pinMode(ms3Pin, OUTPUT); | // Pin 13 es SALIDA

// Activar modo 1/16 microstepping (todos en HIGH) // Esto hace que el motor se mueva 16 veces más suave
digitalWrite(ms1Pin, HIGH); | // MS1 = HIGH
digitalWrite(ms2Pin, HIGH); | // MS2 = HIGH
digitalWrite(ms3Pin, HIGH); | // MS3 = HIGH
// ¡Ahora el motor dará 3200 pasos por vuelta en vez de 200! // Cada paso es 16 veces más pequeño = movimiento SÚPER suave

// --- PASO 12.3: CONFIGURAR EL PIN DEL CALEFACTOR ---
pinMode(mosfetPin, OUTPUT); | // Pin 11 es SALIDA
digitalWrite(mosfetPin, LOW); | // Apagarlo al inicio (por seguridad)
// LOW = 0 voltios = APAGADO

// --- PASO 12.4: CONFIGURAR LOS PINES DE LOS BOTONES ---
// "INPUT_PULLUP" significa: "este pin va a ESCUCHAR (INPUT) y además // tiene una resistencia interna activada que lo mantiene en HIGH cuando // no está presionado"
//
// Cuando presionamos el botón, el pin baja a LOW.
// Cuando soltamos el botón, el pin vuelve a HIGH.

pinMode(botonInversion, INPUT_PULLUP); // Escuchar el botón de inversión
pinMode(botonOnOff, INPUT_PULLUP); | // Escuchar el botón ON/OFF
pinMode(botonBajar, INPUT_PULLUP); | // Escuchar el botón bajar
pinMode(botonSubir, INPUT_PULLUP); | // Escuchar el botón subir

// --- PASO 12.5: PONER EL MOTOR EN DIRECCIÓN "ADELANTE" ---digitalWrite(dirPin, direccionActual); // Escribir HIGH en el pin de dirección // HIGH = adelante, LOW = atrás

// --- PASO 12.6: CONFIGURAR EL TIMER1 ---
// El Timer1 es como un "reloj interno" del Arduino que cuenta el tiempo.
// Lo vamos a configurar para que genere una "alarma" cada pocos microsegundos. // Cada vez que suena la alarma, se ejecuta la función ISR que mueve el motor. //
// ¿Por qué hacemos esto? Porque así el motor se mueve SOLITO en segundo plano, // y el Arduino puede hacer otras cosas al mismo tiempo (leer botones, actualizar // el display, controlar la temperatura, etc.)

noInterrupts(); // Apagar TODAS las interrupciones temporalmente
// Es como decir "shhh, necesito concentrarme un momento"

// Poner los registros del Timer1 en cero (resetear todo)
TCCR1A = 0; | // Timer Counter Control Register 1 A = 0
TCCR1B = 0; | // Timer Counter Control Register 1 B = 0
TCNT1 = 0; | // Timer Counter 1 = 0 (el contador empieza en cero)

// Configurar el Timer1 en modo CTC (Clear Timer on Compare Match)
// En este modo, el timer cuenta hasta un número que nosotros elegimos,
// y cuando llega a ese número, se "resetea" a cero y genera una interrupción. TCCR1B |= (1 << WGM12); // Activar modo CTC
// (Esto es configuración avanzada, no te preocupes por entenderlo)

// Configurar el "prescaler" del timer
// El prescaler es como un "divisor de velocidad".
// El Arduino funciona a 16 MHz (16 millones de pulsos por segundo). // Con prescaler de 8, el timer cuenta cada 0.5 microsegundos. TCCR1B |= (1 << CS11); // Prescaler = 8

// Configurar el valor de comparación
// Cuando el timer llegue a este número, generará una interrupción. OCR1A = 10000; // Output Compare Register 1 A = 10000
// Con prescaler 8, esto equivale a 5000 microsegundos (5 milisegundos) // Cada 5ms sonará la "alarma" y se moverá el motor

// Activar la interrupción por comparación
TIMSK1 |= (1 << OCIE1A); // Timer Interrupt Mask Register 1 // Esto le dice al Arduino: "cuando el timer llegue a OCR1A, // ejecutá automáticamente la función ISR"

interrupts(); // Volver a encender todas las interrupciones // Es como decir "ok, ya terminé de configurar, podés seguir" }

// ============================================
// PASO 13: FUNCIÓN LOOP (SE EJECUTA CONSTANTEMENTE)
// ============================================
// La función "loop" es como el "latido del corazón" del Arduino.
// Se ejecuta una y otra y otra vez, miles de veces por segundo, PARA SIEMPRE. //
// Mientras el Arduino esté encendido, esta función se repite infinitamente: // loop() -> loop() -> loop() -> loop() -> loop() -> ...
//
// Aquí ponemos todo lo que el Arduino tiene que hacer continuamente:
// - Leer botones
// - Leer el potenciómetro
// - Medir temperatura
// - Controlar el calefactor // - Actualizar el display

void loop() {

// --- VARIABLES "STATIC" ---
// "static" significa: "esta variable MANTIENE su valor entre cada vuelta del loop" // Normalmente, las variables se "olvidan" cuando termina la función.
// Pero las variables "static" son como tener "buena memoria":
// recuerdan su valor la próxima vez que se ejecuta la función.

static unsigned long tiempoUltimoCambioMotor = 0; // Guarda CUÁNDO fue el último cambio de velocidad/dirección
// "unsigned long" = número entero positivo MUY grande
// Sirve para guardar tiempos (milisegundos)

// ============================================
// SECCIÓN 1: LEER LOS BOTONES
// ============================================
// Vamos a leer los 4 botones, pero NO todo el tiempo.
// Los leeremos solo cada 50 milisegundos (20 veces por segundo).
// ¿Por qué? Para no "molestar" al programa leyendo todo el tiempo.

static unsigned long tiempoUltimaLecturaBotones = 0; // Guarda CUÁNDO fue la última vez que leímos los botones

// Variables para recordar el estado ANTERIOR de cada botón
// Necesitamos saber si el botón cambió de NO PRESIONADO a PRESIONADO
static bool botonInversionAnterior = HIGH; // HIGH = no presionado static bool botonOnOffAnterior = HIGH;
static bool botonBajarAnterior = HIGH;
static bool botonSubirAnterior = HIGH;

// Pregunta: ¿Ya pasaron 50 milisegundos desde la última lectura?
if (millis() - tiempoUltimaLecturaBotones > 50) {
// millis() = número de milisegundos desde que se encendió el Arduino
// Es como un cronómetro que nunca se detiene

tiempoUltimaLecturaBotones = millis(); // Actualizar el tiempo de la última lectura

// --- BOTÓN DE INVERSIÓN (cambiar dirección del motor) ---
bool botonInversionActual = digitalRead(botonInversion); // Leer el estado ACTUAL del botón
// HIGH = no presionado, LOW = presionado

// Detectar si el botón cambió de "no presionado" a "presionado" if (botonInversionAnterior == HIGH && botonInversionActual == LOW) { // ¡El botón fue PRESIONADO!

direccionActual = !direccionActual; // Invertir la dirección
// ! significa "lo contrario"
// Si era HIGH (adelante), ahora es LOW (atrás) // Si era LOW (atrás), ahora es HIGH (adelante)

digitalWrite(dirPin, direccionActual); // Escribir la nueva dirección al motor

tiempoUltimoCambioMotor = millis(); // Guardar el momento en que cambió
// Esto hará que el display muestre velocidad/dirección por 3 segundos
}
botonInversionAnterior = botonInversionActual; // Recordar el estado actual para la próxima vez

// --- BOTÓN ON/OFF DEL CALEFACTOR ---
bool botonOnOffActual = digitalRead(botonOnOff); // Leer el botón

if (botonOnOffAnterior == HIGH && botonOnOffActual == LOW) {
// ¡El botón fue PRESIONADO!

controlCalefactorActivo = !controlCalefactorActivo; // Invertir: si estaba ON → OFF, si estaba OFF → ON

if (!controlCalefactorActivo) {
// Si acabamos de APAGAR el control...
digitalWrite(mosfetPin, LOW); // Apagar el calefactor inmediatamente (por seguridad)
}
}
botonOnOffAnterior = botonOnOffActual; // Recordar el estado

// --- BOTÓN BAJAR TEMPERATURA ---
bool botonBajarActual = digitalRead(botonBajar); // Leer el botón

if (botonBajarAnterior == HIGH && botonBajarActual == LOW) {
// ¡El botón fue PRESIONADO!

tempObjetivo -= 5.0; // Restar 5 grados a la temperatura objetivo // -= significa "restar y guardar el resultado"
// Es lo mismo que: tempObjetivo = tempObjetivo - 5.0

if (tempObjetivo < 0) {
// Si la temperatura quedó negativa, ponerla en cero // (no queremos temperaturas negativas) tempObjetivo = 0;
}
}
botonBajarAnterior = botonBajarActual; // Recordar el estado

// --- BOTÓN SUBIR TEMPERATURA ---
bool botonSubirActual = digitalRead(botonSubir); // Leer el botón

if (botonSubirAnterior == HIGH && botonSubirActual == LOW) {
// ¡El botón fue PRESIONADO!

tempObjetivo += 5.0; // Sumar 5 grados a la temperatura objetivo // += significa "sumar y guardar el resultado"

if (tempObjetivo > 270) {
// Si la temperatura quedó muy alta, limitarla a 270°C
// (por seguridad, no queremos más de 270°C) tempObjetivo = 270;
}
}
botonSubirAnterior = botonSubirActual; // Recordar el estado }

// ============================================

// SECCIÓN 2: LEER EL POTENCIÓMETRO Y CONTROLAR LA VELOCIDAD
// ============================================
// El potenciómetro (perilla giratoria) controla la velocidad del motor.
// Lo leemos solo cada 50 milisegundos (igual que los botones).

static unsigned long tiempoUltimaLecturaPot = 0; // Cuándo fue la última lectura
static int valorPot = 512; | // Valor actual del potenciómetro (0 a 1023)
| // 512 es el "punto medio"
static int delayMotor = 5000; | // Tiempo entre pasos del motor (en microsegundos)
static bool motorApagado = false; // ¿Está el motor apagado?

// Pregunta: ¿Ya pasaron 50 milisegundos?
if (millis() - tiempoUltimaLecturaPot > 50) {
tiempoUltimaLecturaPot = millis(); // Actualizar el tiempo

// Leemos el potenciómetro VARIAS VECES y promediamos
// ¿Por qué? Porque las lecturas pueden "saltar" un poco (tener ruido eléctrico) // Al promediar varias lecturas, obtenemos un valor más estable y confiable
int suma = 0; // Variable para guardar la suma de todas las lecturas

for (int i = 0; i < 5; i++) {
// Este "for" se repite 5 veces
// i empieza en 0, luego 1, luego 2, luego 3, luego 4, y ahí termina

suma += analogRead(potPin); // Leer el potenciómetro y sumar al total
| // analogRead() lee un valor entre 0 y 1023
| // 0 = perilla totalmente a la izquierda
| // 1023 = perilla totalmente a la derecha

delayMicroseconds(100); // Esperar 100 microsegundos entre lecturas
| // Es una pausa muy pequeñita
}

valorPot = suma / 5; // Calcular el promedio (dividir la suma entre 5) // Esto nos da un valor más estable

// Ahora convertimos el valor del potenciómetro en velocidad del motor
// NOTA: Los rangos están ajustados para microstepping 1/16
// Con 1/16, el motor necesita dar 16 veces más pasos para la misma velocidad física

if (valorPot < 20) {
// Si el potenciómetro está casi en cero (menos de 2%)...
// APAGAR el motor
motorApagado = true;
motorHabilitado = false; // Desactivar el motor (la ISR ya no lo moverá)

} else {
// Si el potenciómetro tiene algún valor...
// ENCENDER el motor
motorApagado = false;
motorHabilitado = true; // Activar el motor

// Calcular el delay (tiempo entre pasos) según el valor del potenciómetro // Los valores están AJUSTADOS para microstepping 1/16
// Ahora los delays son más cortos porque necesitamos más pasos

if (valorPot < 400) {

// Rango bajo (20 a 400): velocidades lentas
delayMotor = map(valorPot, 20, 400, 3000, 1500);
// AJUSTADO: valores más bajos que antes para compensar microstepping // Si valorPot es 20 → delayMotor será 3000 (lento pero suave)
// Si valorPot es 400 → delayMotor será 1500

} else if (valorPot > 600) {
// Rango alto (600 a 1023): velocidades rápidas
delayMotor = map(valorPot, 600, 1023, 1000, 200);
// AJUSTADO: valores más bajos para velocidades más altas // Si valorPot es 600 → delayMotor será 1000
// Si valorPot es 1023 → delayMotor será 200 (rápido y suave)

} else {
// Rango medio (400 a 600): velocidad media fija
delayMotor = 1200; // AJUSTADO: velocidad media para 1/16 }

// Actualizar la velocidad OBJETIVO (no la actual)
// La ISR se encargará de acelerar/desacelerar gradualmente
motorDelayObjetivo = delayMotor; // ¡CAMBIO IMPORTANTE! Ahora usamos aceleración suave
}
}

// ============================================
// SECCIÓN 3: MEDIR TEMPERATURA Y CONTROLAR EL CALEFACTOR // ============================================
// Aquí leemos el termistor, calculamos la temperatura,
// ejecutamos el algoritmo PID, y actualizamos el display.
// Todo esto se hace cada 200 milisegundos (5 veces por segundo).

static float temperaturaActual = 0.0; // Temperatura medida (en °C)
static int valorPotAnterior = 0; | // Valor anterior del potenciómetro (para
detectar cambios)
static unsigned long tiempoUltimaActualizacionDisplay = 0; // Cuándo fue la última actualización

// Pregunta: ¿Ya pasaron 200 milisegundos?
if (millis() - tiempoUltimaActualizacionDisplay > 200) { tiempoUltimaActualizacionDisplay = millis(); // Actualizar el tiempo

// --- PASO 3.1: LEER EL TERMISTOR Y CALCULAR TEMPERATURA ---
// Leemos el termistor MUCHAS VECES (10 veces) y promediamos.
// ¿Por qué? Para que la lectura sea MUY estable y no "salte".

float sumaTemperaturas = 0; // Variable para sumar todas las temperaturas

for (int i = 0; i < 10; i++) {
// Este "for" se repite 10 veces

int lecturaADC = analogRead(termistorPin); // Leer el pin del termistor
| // Obtenemos un número entre 0 y 1023

// CALCULAR LA RESISTENCIA DEL TERMISTOR
// Usamos la fórmula del divisor de tensión:

// El circuito es: 5V → R_FIJA (4.7k) → [punto medio] → TERMISTOR → GND // En el "punto medio" es donde medimos (pin A1)
//
// Fórmula: R_termistor = R_fija × (ADC / (1023 - ADC))
float resistenciaTermistor = R_FIJA * lecturaADC / (1023.0 - lecturaADC);

// CALCULAR TEMPERATURA USANDO LA ECUACIÓN DE STEINHART-HART
// Esta es una fórmula matemática que convierte resistencia en temperatura. // Es un poco complicada, pero funciona muy bien.
//
// La fórmula completa es:
// 1/T = 1/T0 + (1/B) × ln(R/R0)
// Donde:
// - T = temperatura en Kelvin (la que queremos calcular) // - T0 = 298.15 K (que es 25°C en Kelvin)
// - B = 3950 (constante BETA del termistor)
// - R = resistencia actual del termistor
// - R0 = 100000 ohmios (resistencia del termistor a 25°C) // - ln = logaritmo natural

float steinhart;
steinhart = resistenciaTermistor / R_TERMISTOR_25C; // R / R0
steinhart = log(steinhart); | // ln(R / R0)
steinhart /= BETA; | // (1/B) × ln(R/R0)
steinhart += 1.0 / 298.15; | // + 1/T0
steinhart = 1.0 / steinhart; | // Invertir para obtener T

float tempLectura = steinhart - 273.15; // Convertir de Kelvin a Celsius
| // (Celsius = Kelvin - 273.15)

sumaTemperaturas += tempLectura; // Sumar esta lectura al total

delayMicroseconds(100); // Pequeña pausa entre lecturas
}

// Calcular el PROMEDIO de las 10 lecturas
float tempInstantanea = sumaTemperaturas / 10.0; // Dividir la suma entre 10

// FILTRO ADICIONAL: SUAVIZADO EXPONENCIAL
// Esto hace que la temperatura cambie "suavemente" en el display,
// en vez de saltar de un número a otro.
// Es como mezclar la temperatura nueva con la anterior:
// 80% de la anterior + 20% de la nueva = cambio gradual

if (temperaturaActual == 0.0) {
// Si es la primera lectura, usar el valor directamente temperaturaActual = tempInstantanea;
} else {
// Si no es la primera lectura, mezclar con la anterior temperaturaActual = (temperaturaActual * 0.8) + (tempInstantanea * 0.2); }

// --- PASO 3.2: CONTROL PID DEL CALEFACTOR ---
// El PID es como un "piloto automático" que controla la temperatura. // Calcula cuánta potencia darle al calefactor para llegar exactamente // a la temperatura objetivo, sin pasarse ni quedarse corto.

static int potenciaPWM = 0; | // Potencia que le daremos al calefactor (0 a
255)
static bool calefactorEncendido = false; // ¿Está el calefactor encendido?

if (controlCalefactorActivo) {
// Solo si el control está ACTIVADO (botón ON)...

// Calcular el ERROR
// Error = qué tan lejos estamos del objetivo
// Si estamos a 200°C y queremos 240°C, el error es +40 // Si estamos a 250°C y queremos 240°C, el error es -10 float error = tempObjetivo - temperaturaActual;

// --- COMPONENTE P (PROPORCIONAL) ---
// Cuanto más LEJOS estamos del objetivo, más potencia aplicamos.
// Es como pisar más el acelerador cuando estás más lejos de tu destino. float P = Kp * error;
// Kp = 8.0, entonces si el error es 10°C → P = 80

// --- COMPONENTE I (INTEGRAL) ---
// Sumamos todos los errores que tuvimos en el tiempo.
// Esto corrige errores "persistentes" (que se mantienen mucho tiempo). // Es como compensar por siempre quedarnos un poquito abajo del objetivo. errorAcumulado += error; // Sumar el error actual al total

// Limitar el error acumulado para que no se vaya al infinito
if (errorAcumulado > 1000) errorAcumulado = 1000;
if (errorAcumulado < -1000) errorAcumulado = -1000;

float I = Ki * errorAcumulado;
// Ki = 0.05, entonces si errorAcumulado es 100 → I = 5

// --- COMPONENTE D (DERIVATIVO) ---
// Mira qué tan RÁPIDO está cambiando el error.
// Si el error está bajando muy rápido, significa que nos estamos // acercando MUY RÁPIDO al objetivo, ¡así que FRENA!
// Es como frenar el auto ANTES de llegar al semáforo.
float D = Kd * (error - errorAnterior);
// Kd = 120.0, entonces si el error bajó 2°C desde la última vez → D = -240 // Ese número negativo GRANDE hará que frenemos mucho

errorAnterior = error; // Guardar el error actual para la próxima vez

// --- SUMAR LOS TRES COMPONENTES ---
// La salida del PID es la suma de P + I + D
float salidaPID = P + I + D;

// --- CONVERTIR A PWM (0-255) ---
// PWM es como un "control de potencia" para el calefactor. // 0 = apagado completamente
// 255 = encendido a máxima potencia
// 127 = encendido a "media potencia"

potenciaPWM = (int)salidaPID; // Convertir a número entero

// Limitar entre 0 y 255
if (potenciaPWM > 255) potenciaPWM = 255;
if (potenciaPWM < 0) potenciaPWM = 0;

// --- APLICAR LA POTENCIA AL CALEFACTOR ---
analogWrite(mosfetPin, potenciaPWM); // Escribir el valor PWM al MOSFET // analogWrite() controla la potencia

// Decidir si consideramos al calefactor "encendido"
// Si la potencia es mayor al 10% (25 de 255), está encendido calefactorEncendido = (potenciaPWM > 25);

} else {
// Si el control está DESACTIVADO (botón OFF)...

analogWrite(mosfetPin, 0); // Apagar completamente el calefactor potenciaPWM = 0;
calefactorEncendido = false;

// Resetear las variables del PID
errorAcumulado = 0; // Borrar el error acumulado errorAnterior = 0; // Borrar el error anterior }

// --- PASO 3.3: DETECTAR SI CAMBIÓ LA VELOCIDAD ---
// Si el potenciómetro cambió más de 10 puntos, significa que // el usuario está ajustando la velocidad, así que mostramos // velocidad/dirección en el display por 3 segundos.

if (abs(valorPot - valorPotAnterior) > 10) {
// abs() = valor absoluto (ignora si es positivo o negativo)
// Pregunta: ¿el potenciómetro cambió más de 10 puntos?

tiempoUltimoCambioMotor = millis(); // Marcar el momento del cambio
valorPotAnterior = valorPot; | // Recordar el nuevo valor
}

// --- PASO 3.4: ACTUALIZAR EL DISPLAY ---
// Decidimos QUÉ mostrar en el display según si cambió la velocidad recientemente.

if (millis() - tiempoUltimoCambioMotor < 3000) {
// Si pasaron MENOS de 3 segundos (3000 milisegundos) desde el último cambio... // MOSTRAR VELOCIDAD Y DIRECCIÓN

lcd.setCursor(0, 0); // Ir a la primera línea del display lcd.print("Velocidad: ");

// Calcular el porcentaje de velocidad (0% a 100%)
int velocidadPercent;
if (motorApagado) {
velocidadPercent = 0; // Si el motor está apagado, mostrar 0% } else {

// Convertir el delay del motor en porcentaje // AJUSTADO para microstepping 1/16:
// delay grande (3000) = velocidad baja (0%)
// delay pequeño (200) = velocidad alta (100%) velocidadPercent = map(delayMotor, 3000, 200, 0, 100); // Limitar entre 0 y 100 por seguridad
if (velocidadPercent < 0) velocidadPercent = 0;
if (velocidadPercent > 100) velocidadPercent = 100;
}

// Alinear los números (agregar espacios para que quede bonito)
if (velocidadPercent < 100) lcd.print(" "); // Si es menor a 100, agregar un espacio
if (velocidadPercent < 10) lcd.print(" "); // Si es menor a 10, agregar otro espacio

lcd.print(velocidadPercent); // Mostrar el número
lcd.print("% | "); | // Mostrar el símbolo % y espacios para "limpiar"

lcd.setCursor(0, 1); // Ir a la segunda línea del display
lcd.print("Dir: ");

if (direccionActual == HIGH) {
lcd.print("Adelante "); // Mostrar "Adelante" con espacios al final } else {
lcd.print("Atras "); // Mostrar "Atras" con espacios al final }

} else {
// Si pasaron MÁS de 3 segundos...
// MOSTRAR TEMPERATURA (modo normal)

lcd.setCursor(0, 0); // Ir a la primera línea
lcd.print("T:"); | // Mostrar "T:" (temperatura)
lcd.print(temperaturaActual, 1); // Mostrar temperatura con 1 decimal (ej: 23.5)
lcd.print("C | "); | // Mostrar "C" (Celsius) y espacios

// Mostrar el ESTADO del calefactor: [ON], [--], o [OFF]
if (controlCalefactorActivo) {
// Si el control está activado...
if (calefactorEncendido) {
lcd.print("[ON] "); // Si está calentando, mostrar [ON]
} else {
lcd.print("[--]"); // Si está esperando (sin calentar), mostrar [--] }
} else {
// Si el control está desactivado...
lcd.print("[OFF]"); // Mostrar [OFF]
}

lcd.setCursor(0, 1); // Ir a la segunda línea
lcd.print("Obj:"); // Mostrar "Obj:" (objetivo)
lcd.print(tempObjetivo, 0); // Mostrar temperatura objetivo sin decimales (ej: 240)
lcd.print("C | "); | // Mostrar "C" y espacios para "limpiar"
}
}

}

// ============================================
// ¡FIN DEL PROGRAMA!
// ============================================
// El loop() se repetirá infinitamente mientras el Arduino esté encendido. // El motor se moverá automáticamente gracias a la interrupción del Timer1. // El PID controlará la temperatura de forma inteligente.
// ¡Y todo funcionará al mismo tiempo sin bloquearse! 🎉

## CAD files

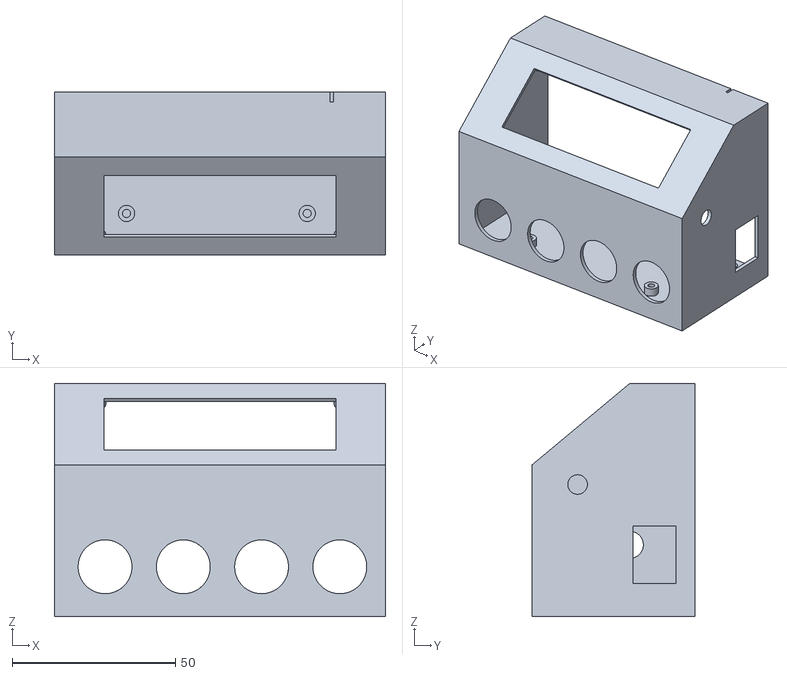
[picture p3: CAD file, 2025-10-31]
Case_con_botones.stl
101.5 x 50.0 x 71.5

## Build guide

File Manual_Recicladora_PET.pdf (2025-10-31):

Esta máquina transforma botellas de plástico PET (las de gaseosa) en "hilo" para impresoras 3D.
¿Cómo funciona? Es como una máquina de hacer fideos, pero con plástico:

### 1. Cortás tiras de botellas de plástico 2. La máquina las derrite a 240°C (muy caliente!) 3. Un motor va tirando del plástico derretido 4. Sale un "hilo" perfecto para usar en impresoras 3D

¡Convertimos basura en algo útil! 🌍💚

La máquina tiene DOS partes principales:

"El Tractorcito Inteligente" 🚜
Esta parte tira del plástico derretido, como cuando sacás masa de pizza estirada.

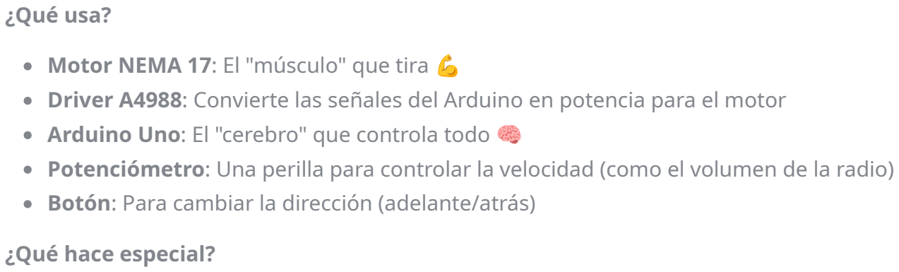
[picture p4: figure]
¿Qué usa?; Motor NEMA 17: El "músculo" que tira 💪; ¿Qué hace especial?

Driver A4988: Convierte las señales del Arduino en potencia para el motor
Arduino Uno: El "cerebro" que controla todo 🧠
Potenciómetro: Una perilla para controlar la velocidad (como el volumen de la radio) Botón: Para cambiar la dirección (adelante/atrás)

Se mueve SÚPER suave (microstepping 1/16 = pasos 16 veces más pequeños) Acelera y frena de forma gradual (no se sacude)
Podés controlar la velocidad de 0% a 100%

# 🔄 Máquina Recicladora de PET ♻️➡️✨

## 📖 ¿Qué es este proyecto?

## ️ ¿Cómo está hecha?

### Parte 1: El Motor (Tira del plástico)

### Parte 2: El Calentador (Derrite el plástico)

"La Cocina de Plástico" 🔥
Esta parte derrite el plástico PET a 240°C (la temperatura perfecta).
¿Qué usa?
Hotend V6: El "horno" que calienta
Termistor NTC 100k: Un "termómetro electrónico" que mide la temperatura Módulo MOSFET: Un interruptor electrónico que controla cuánta potencia darle al calentador
Display LCD: Una pantallita que muestra la temperatura 📺

### 3 Botones: Para prender/apagar y subir/bajar la temperatura

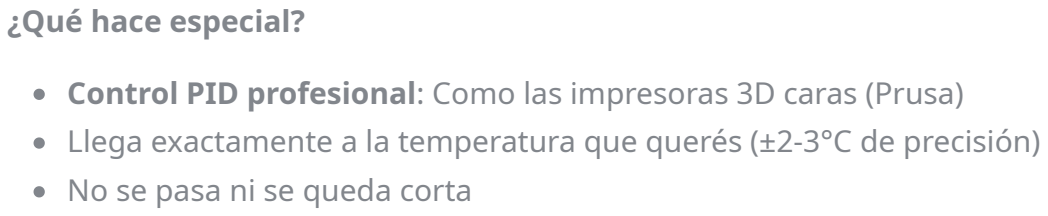
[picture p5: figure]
¿Qué hace especial?; No se pasa ni se queda corta

Control PID profesional: Como las impresoras 3D caras (Prusa) Llega exactamente a la temperatura que querés (±2-3°C de precisión)

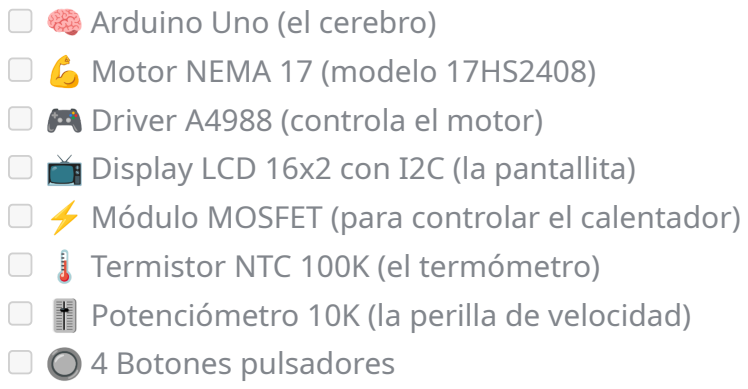
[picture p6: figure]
🧠 Arduino Uno (el cerebro) 💪 Motor NEMA 17 (modelo 17HS2408) 🎮 Driver A4988 (controla el motor); ️ Termistor NTC 100K (el termómetro); 🔘 4 Botones pulsadores

📺 Display LCD 16x2 con I2C (la pantallita)
⚡ Módulo MOSFET (para controlar el calentador)

️ Potenciómetro 10K (la perilla de velocidad)

🔥 Hotend V6 (el calentador)
🔌 Fuente de alimentación 24V
🔽 Módulo Step-down LM2596 (convierte 24V a 12V)
🔧 Resistencia 4.7kΩ (para el termómetro)
⭐ Resistencia 2.2kΩ (evita que el motor vibre al encender)
🔗 Cable jumper (para conectar 2 pines del A4988)
🛑 Botón de emergencia (para cortar todo en caso de problema)

## 📋 ¿Qué materiales necesito?

### Electrónica:

### Componentes importantes:

1. 📥 Descargá Arduino IDE desde arduino.cc
2. ️ Instalalo en tu computadora
1. 📥 Descargá este proyecto (botón verde "Code" → "Download ZIP")
2. 📂 Descomprimí el archivo ZIP
1. ️ Abrí Arduino IDE
2. 🔧 Andá a: Herramientas → Administrar Bibliotecas
3. 🔍 Buscá: "LiquidCrystal I2C"
4. ✅ Instalá la versión de Frank de Brabander

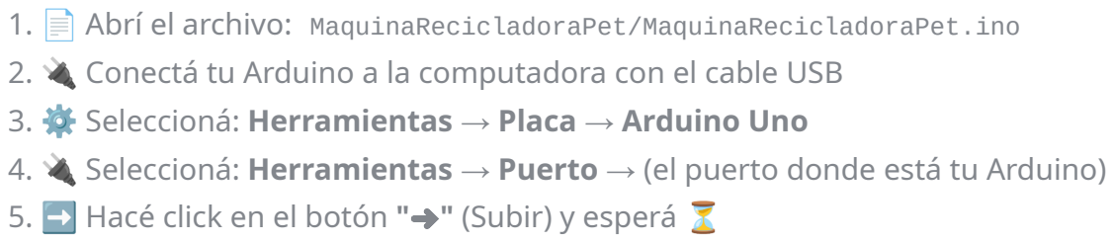
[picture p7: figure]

1. 📄 Abrí el archivo: MaquinaRecicladoraPet/MaquinaRecicladoraPet.ino
2. 🔌 Conectá tu Arduino a la computadora con el cable USB
3. ⚙️ Seleccioná: Herramientas → Placa → Arduino Uno
4. 🔌 Seleccioná: Herramientas → Puerto → (el puerto donde está tu Arduino)
5. ➡️ Hacé click en el botón "➜" (Subir) y esperá ⏳

Cuando encendés el Arduino, durante los primeros 3 segundos el motor puede vibrar o girar solo. Esto pasa porque los cables "flotan" (no tienen un valor definido) hasta que el programa arranca.
✅ Solución (OBLIGATORIA):

En el módulo A4988, buscá los pines RST y SLP (están uno al lado del otro). Conectalos con un cable o jumper.

## 🚀 ¿Cómo lo instalo?

### Paso 1: Instalar el programa Arduino IDE 💻

### Paso 2: Descargar este proyecto 📦

### Paso 3: Instalar la biblioteca del display 📚

### Paso 4: Subir el código al Arduino ⬆️

## ⚠️ IMPORTANTE: Configuración de Hardware

### 🔊 Problema común: Motor vibra al encender

1. 🔗 Conectar dos pines del A4988 juntos
2. ⭐ Agregar una resistencia al pin STEP

Esta es LA SOLUCIÓN más importante:

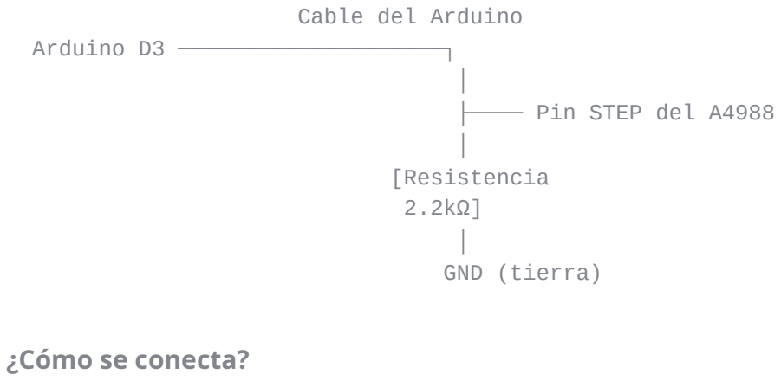
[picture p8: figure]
¿Cómo se conecta?; Cable del Arduino Arduino D3 ────────────────────┐; │ ├──── Pin STEP del A4988 │ [Resistencia 2.2kΩ] │ GND (tierra)

NO desconectes el cable que va del Arduino al A4988
Agregá una resistencia de 2.2kΩ entre el pin STEP del A4988 y GND
La resistencia va "en paralelo" (al costado), no corta el cable
Podés usar resistencias de: 2.2kΩ, 4.7kΩ o 10kΩ
¿Por qué funciona? La resistencia "tira" el pin hacia GND (0 voltios) cuando el Arduino no está mandando señales. Así el motor no se mueve durante el arranque.

El microstepping hace que el motor se mueva SÚPER suave, sin vibraciones. Tenés que

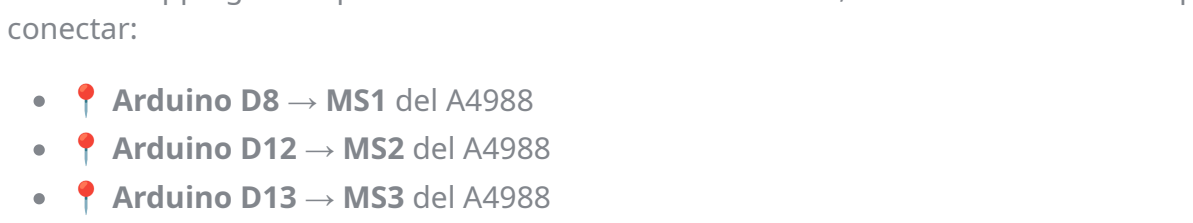
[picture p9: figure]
conectar:; 📍 Arduino D8 → MS1 del A4988 📍 Arduino D12 → MS2 del A4988 📍 Arduino D13 → MS3 del A4988

Estos 3 pines le dicen al motor que se mueva en pasos 16 veces más pequeños (3200 pasos por vuelta en vez de 200). ¡Por eso el movimiento es tan suave!

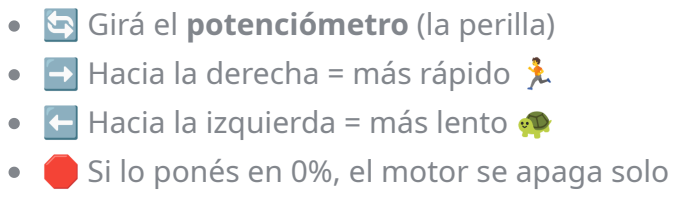
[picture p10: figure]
🔄 Girá el potenciómetro (la perilla) ➡️ Hacia la derecha = más rápido 🏃 ⬅️ Hacia la izquierda = más lento 🐢

🛑 Si lo ponés en 0%, el motor se apaga solo

3. 🎯 Conectar los pines de microstepping (IMPORTANTE para movimiento suave)

## 🎮 ¿Cómo se usa?

### ️ Controlar la velocidad del motor:

### 🔀 Cambiar la dirección:

🔘 Presioná el botón conectado al pin D4 ↔️ El motor cambia entre adelante y atrás

🔘 Botón conectado al pin D5: Prender/Apagar el calentador 🔥 🔘 Botón conectado al pin D6: Bajar temperatura (de a 5°C) ❄️ 🔘 Botón conectado al pin D7: Subir temperatura (de a 5°C) 🔥 🎯 Temperatura inicial: 240°C (perfecta para PET)

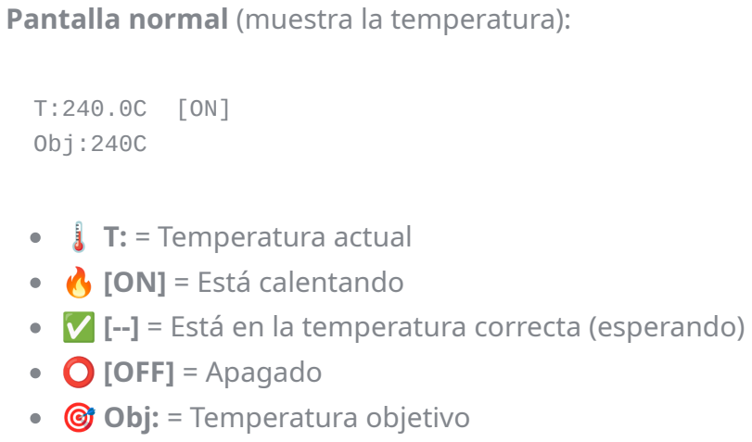
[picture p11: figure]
Pantalla normal (muestra la temperatura):; ️ T: = Temperatura actual 🔥 [ON] = Está calentando; ⭕ [OFF] = Apagado 🎯 Obj: = Temperatura objetivo; T:240.0C [ON] Obj:240C

✅ [--] = Está en la temperatura correcta (esperando)

Pantalla temporal (cuando ajustás la velocidad):

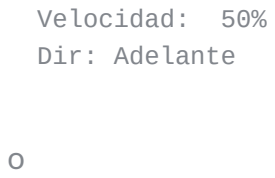
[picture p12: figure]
Velocidad: 50% Dir: Adelante

⏱️ Esta pantalla se muestra por 3 segundos cuando tocás el potenciómetro o el botón de dirección.

❓ Causa: Los cables "flotan" durante los primeros 3 segundos del arranque.

### ️ Controlar la temperatura:

### 📺 Leer el display:

## 🔧 Solución de problemas

### 🔊 El motor vibra cuando enciendo el Arduino

✅ Solución:
1. ❓ ¿Conectaste los pines RST y SLP del A4988?
2. ❓ ¿Agregaste la resistencia 2.2kΩ entre STEP y GND?
3. ❓ ¿La resistencia está en paralelo (no corta el cable del Arduino)? ✨ Si hiciste todo eso, el motor NO debería moverse al encender.

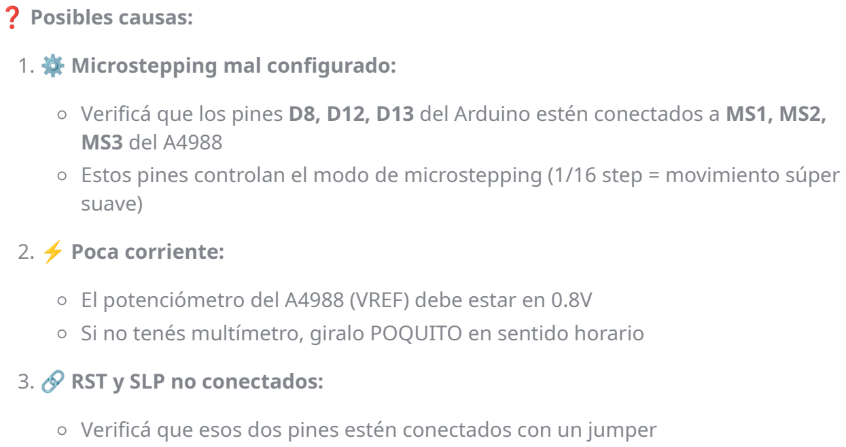
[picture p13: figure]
❓ Posibles causas:; 1. ⚙️ Microstepping mal configurado:; MS3 del A4988; suave); 2. ⚡ Poca corriente:; 3. 🔗 RST y SLP no conectados:

Verificá que los pines D8, D12, D13 del Arduino estén conectados a MS1, MS2,

Estos pines controlan el modo de microstepping (1/16 step = movimiento súper

El potenciómetro del A4988 (VREF) debe estar en 0.8V
Si no tenés multímetro, giralo POQUITO en sentido horario

Verificá que esos dos pines estén conectados con un jumper

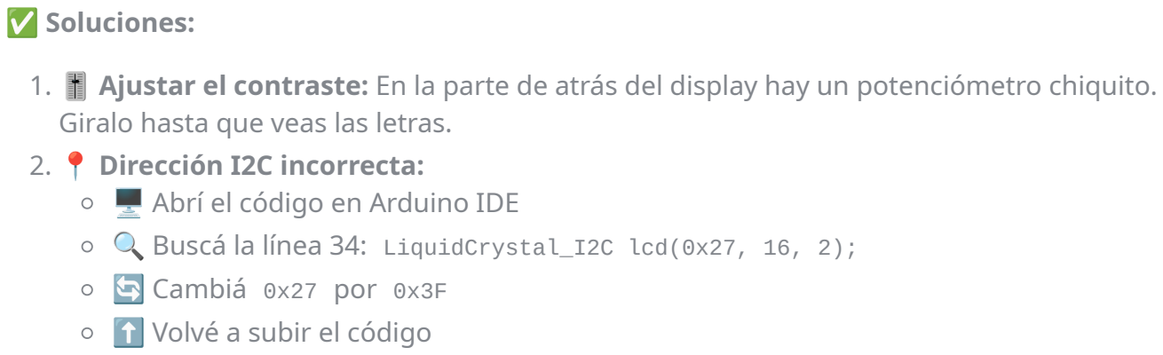
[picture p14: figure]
✅ Soluciones:; Giralo hasta que veas las letras. 2. 📍 Dirección I2C incorrecta: ️ Abrí el código en Arduino IDE; 🔄 Cambiá 0x27 por 0x3F ⬆️ Volvé a subir el código

1. ️ Ajustar el contraste: En la parte de atrás del display hay un potenciómetro chiquito.

🔍 Buscá la línea 34: LiquidCrystal_I2C lcd(0x27, 16, 2);

1. 🔍 Verificá las conexiones del termistor (el sensor de temperatura)
2. 🔧 Verificá la resistencia de 4.7kΩ (debe estar bien conectada)

### 🔊 El motor vibra TODO el tiempo

### 📺 El display no muestra nada

### ️ La temperatura no es correcta

3. 🏠 La temperatura ambiente debería mostrar entre 18°C y 25°C

⚙️ Pasos por vuelta: 3200 (con microstepping 1/16)
🏃 Velocidad: Ajustable de 100 a 2000 RPM
✨ Suavidad: Movimiento ultra suave, sin vibraciones
🚀 Aceleración: Gradual (no se sacude al arrancar/frenar)

🧠 Control: PID profesional (como impresoras 3D Prusa)

📐 Tamaño: 16 caracteres × 2 líneas
⚡ Actualización: Cada 0.2 segundos (sin parpadeo)

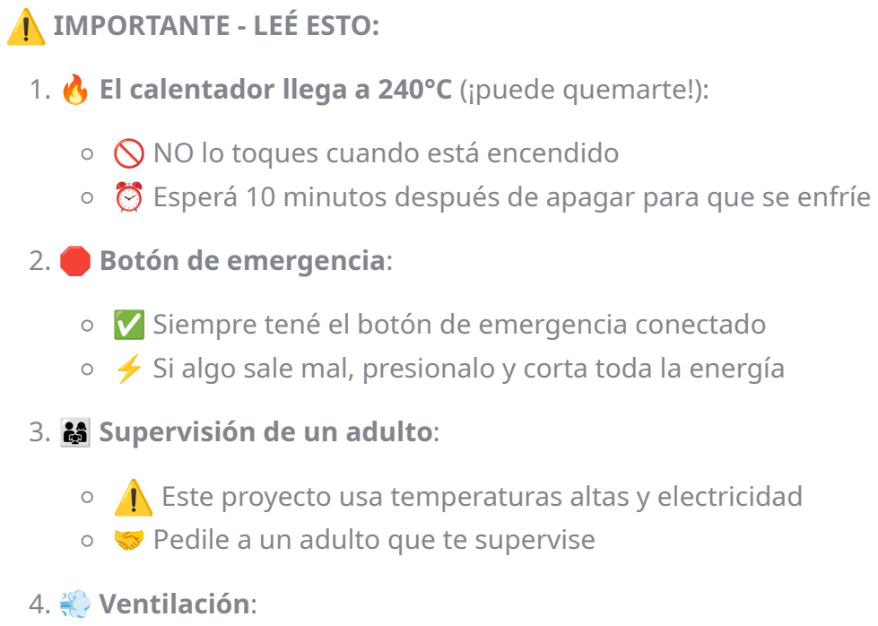
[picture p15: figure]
⚠️ IMPORTANTE - LEÉ ESTO:; 🚫 NO lo toques cuando está encendido; 2. 🛑 Botón de emergencia:; 3. 👨‍👩‍👧 Supervisión de un adulto:; 🤝 Pedile a un adulto que te supervise; 4. 💨 Ventilación:

1. 🔥 El calentador llega a 240°C (¡puede quemarte!):

⏰ Esperá 10 minutos después de apagar para que se enfríe

✅ Siempre tené el botón de emergencia conectado
⚡ Si algo sale mal, presionalo y corta toda la energía

⚠️ Este proyecto usa temperaturas altas y electricidad

## 📊 Datos técnicos (para los curiosos) 🤓

### 🎮 Motor:

### ️ Temperatura:

### 📺 Display:

## ️ Seguridad

🪟 Usá la máquina en un lugar ventilado 👃 El plástico derretido puede tener olor

📚 Documentación oficial de Arduino (https://www.arduino.cc/reference/es/) 🎥 Tutoriales en español (https://www.arduino.cc/en/Tutorial/HomePage)

🥤 El PET es el plástico de las botellas de gaseosa

♻️ Precious Plastic (https://preciousplastic.com/) - Proyecto de reciclaje de plástico global 🤖 Recyclebot (https://www.appropedia.org/Recyclebot) - Máquinas similares

🌍 Queremos ayudar al planeta convirtiendo botellas de plástico (que iban a la basura) en material útil para crear cosas nuevas con impresoras 3D.
Si cada persona recicla sus botellas, podemos:

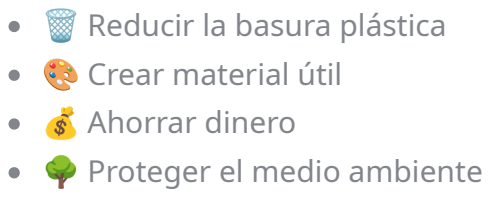
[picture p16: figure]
️ Reducir la basura plástica 🎨 Crear material útil 💰 Ahorrar dinero 🌳 Proteger el medio ambiente

¡Juntos podemos convertir la basura en tesoros! 🌍♻️✨

Este proyecto es libre y gratuito (Licencia MIT). Podés:

## 🎓 ¿Querés aprender más?

### 🤖 Sobre Arduino:

### ♻️ Sobre el PET:

### 🌍 Sobre reciclaje:

## 💚 Misión del proyecto

## 📄 Licencia

🤝 Compartirlo
️ Construir tu propia máquina

Creado con ❤️ para ayudar al planeta 🌍 y enseñar programación 💻.

## 👥 Créditos

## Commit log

2025-10-14 Add LCD I2C display support to show speed and direction
    The display shows real-time feedback without affecting motor performance by updating only every 2000 steps. Connected via I2C to pins A4 (SDA) and A5 (SCL).
2025-10-17 Add thermistor temperature monitoring with NTC 100k
    Added temperature reading from NTC 100k thermistor connected to A1 with 4.7k voltage divider. Display shows current temperature and temporarily switches to speed/direction when potentiometer is adjus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
2025-10-17 Add heater control with MOSFET and control buttons
    Added automatic temperature control system with three buttons:
    - D5: ON/OFF toggle for heater control
    - D6: Lower target temperature (-5°C per press)
    - D7: Raise target temperature (+5°C per press)
    Features:
    - Temperature range: 0-270°C
    - Hysteresis control (2°C) to prevent rapid cycling
    - Display shows current temp, target, and heater status (HEAT/WAIT/OFF)
    - Auto safety shutoff when control is disabled
    [MaquinaRecicladoraPet.ino]
2025-10-17 Optimize motor control and improve temperature display
    Major improvements:
    - Removed blocking delays - buttons now read every 50ms without interrupting motor
    - Motor shuts off below 2% speed for clean stops
    - Temperature control with 10°C anticipation to prevent overshoot
    - Professional display with [ON]/[OFF]/[--] status indicators
    - Spanish direction labels (Adelante/Atras)
    - Cleaner T: and Obj: temperature display format
    Motor now runs smoothly without skipping steps while all controls remain responsive.
    [MaquinaRecicladoraPet.ino]
2025-10-20 Add temperature reading stabilization with dual filtering
    Implemented two-stage temperature smoothing:
    - Takes 10 thermistor readings and averages them
    - Applies exponential smoothing filter (80% previous + 20% new)
    This eliminates display jitter and provides stable, professional temperature readings while still responding to real temperature changes.
    [MaquinaRecicladoraPet.ino]
2025-10-20 Implement PID temperature control and Timer1 motor interrupts
    Major improvements for professional control:
    Temperature Control:
    - Replaced ON/OFF control with PID algorithm (like Prusa printers)
    - Default target temperature set to 150°C for PET
    - PWM power control prevents overshoot (150°C instead of 190°C)
    - Kp=10, Ki=0.1, Kd=50 for smooth temperature regulation
    Motor Control:
    - Timer1 hardware interrupts for step generation
    - Motor runs independently in background with zero interference
    - Display updates no longer cause motor stuttering
    - Perfect for precision plastic extrusion
    Display:
    - Velocity/direction only shown when manipulating controls
    - 3-second temporary display, then retu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
    [MaquinaRecicladoraPet.ino]
2025-10-20 Fix motor stuttering when heater is ON - move MOSFET to pin 11
    Problem: Pin 9 uses Timer1 for PWM, which conflicts with Timer1 used for motor control
    Solution: Moved MOSFET from pin D9 to pin D11 (uses Timer2)
    Hardware change required:
    - Move MOSFET signal wire from D9 to D11
    Now motor and heater operate independently without interference.
    [MaquinaRecicladoraPet.ino]
2025-10-22 Adjust PID parameters to reduce overshoot at 240°C target
    Changed temperature target from 150°C to 240°C and tuned PID values:
    - Kp: 10 → 8 (gentler proportional response)
    - Ki: 0.1 → 0.05 (less integral windup during heating)
    - Kd: 50 → 120 (much stronger derivative braking)
    The increased Kd makes the system anticipate and brake much earlier when approaching target temperature, preventing overshoot while maintaining excellent steady-state control.
    [MaquinaRecicladoraPet.ino]
2025-10-22 Update documentation to reflect completed PID temperature control system
    - Mark heating system as completed in architecture section
    - Update hardware list: move LCD, MOSFET, thermistor, and control buttons to implemented
    - Document full software implementation including Timer1/Timer2 architecture
    - Add detailed technical specifications for both traction and heating systems
    - Include installation guide with LiquidCrystal_I2C library setup
    - Add operation instructions for temperature control
    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
2025-10-22 Correct power supply configuration in BOM
    - Update to reflect 24V primary power supply
    - Move Step-down LM2596 to implemented hardware
    - Document voltage conversion (24V → 12V for Arduino and motor)
    - Remove redundant pending items
2025-10-22 Add emergency button and Hotend V6 to implemented hardware
    - Move emergency button from pending to implemented
    - Move Hotend V6 from pending to implemented
    - All hardware components are now complete
2025-10-24 Improve code comments for educational purposes
    Completely rewrite all code comments to make them accessible and
    educational for 12-year-old beginners with no programming experience.
    Changes:
    - Add detailed step-by-step explanations of every code section
    - Include simple analogies (alarm clock, accelerator, thermometer)
    - Define all technical terms (ISR, PWM, PID, volatile, Timer, etc.)
    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
2025-10-29 Add 1/16 microstepping and smooth acceleration to eliminate motor vibration
    This is a CRITICAL fix for motor vibration issues, implementing techniques
    from professional 3D printer firmwares (Marlin, Prusa).
    ## Problem Analysis:
    The motor was operating in FULL-STEP mode (MS1/MS2/MS3 = LOW by default),
    causing 1.8° jumps per step, resulting in severe mechanical vibration.
    Additionally, instantaneous speed changes caused jerking and resonance.
    ## Solution Implemented:
    ### 1. Microstepping 1/16 Configuration
    - Added pins D8, D12, D13 for MS1, MS2, MS3 control
    - Configure all MS pins to HIGH in setup() for 1/16 microstepping
    - Motor now takes 3200 steps/revolution instead of 200
    - Each step i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
    [MaquinaRecicladoraPet.ino]
2025-10-30 Document hardware solution for A4988 startup vibration issue
    Added comprehensive documentation for the critical pull-down resistor solution:
    Hardware updates:
    - Added 2.2kΩ pull-down resistor to BOM (STEP pin → GND)
    - Added RST-SLP jumper connection requirement
    - Documented proper wiring diagram for pull-down resistor
    Documentation improvements:
    - New "Critical Hardware Configuration" section with detailed instructions
    - New "Troubleshooting" section with common issues and solutions
    - Updated technical specifications to reflect 1/16 microstepping
    - Clarified that pull-down resistor goes IN PARALLEL (doesn't interrupt Arduino connection)
    - Added visual ASCII diagram for resistor placemen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
2025-10-31 Add emojis to README and fix inconsistencies with code
    - Add emojis throughout README to make it more engaging for kids
    - Fix button pin descriptions (D4, D5, D6, D7)
    - Add microstepping pins section (D8→MS1, D12→MS2, D13→MS3)
    - Clarify display shows "Dir: Atras" (without accent)
    - Add 3D case files (STL files and FreeCAD script)
    - Remove "Última actualización: Octubre 2025" line
    - Remove star emoji and "CRÍTICA" from 2.2kΩ resistor line
    - Verify all technical values match the code implementation
    [Case_con_botones.stl, case.stl, case_back.stl]
2025-10-31 Remove unused STL files and FreeCAD script
    Removed obsolete 3D case files that are no longer needed.
    [case.stl, case_back.stl]
2025-10-31 Add printable PDFs for students
2025-11-03 Add hardware connection schematic
